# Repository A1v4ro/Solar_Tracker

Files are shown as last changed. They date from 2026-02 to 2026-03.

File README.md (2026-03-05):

# Sistema Autónomo Portátil de Control de Seguimiento Solar

## 📌 Descripción

Este proyecto corresponde al desarrollo de un **sistema autónomo portátil de seguimiento solar** orientado a maximizar la captación de energía en módulos fotovoltaicos de baja potencia.

El sistema integra control basado en lógica difusa, registro de datos, supervisión web y alimentación autónoma en un diseño compacto y funcional.

Proyecto académico desarrollado como trabajo final de Ingeniería Electrónica.

---

## 🎯 Objetivo

Diseñar e implementar un sistema electrónico portátil capaz de optimizar la orientación de un panel fotovoltaico mediante control inteligente, incrementando la eficiencia de captación energética respecto a un sistema fijo.

---

## 🧠 Arquitectura del Sistema

El sistema está compuesto por:

- Sensor solar basado en LDRs
- Controlador difuso tipo Sugeno
- Control PWM para motores DC
- Puente H L298N con aislamiento
- Sistema de registro de datos (microSD + RTC DS3231)
- Módulo de alimentación autónoma con batería 18650
- Interfaz HMI basada en servidor web
- Prototipo mecánico diseñado en SolidWorks

---

## 📂 Estructura del Repositorio

```
/Codigo Seguidor Solar      → Firmware del microcontrolador (platformio)
/XFUZZY controlador         → Diseño del controlador difuso (Xfuzzy)
/Mecanismo Seguidor Solar   → Modelo mecánico del prototipo (SolidWorks)
/PCB KiCad                  → Diseño de la PCB (esquemático y layout)
```

---

# 🔧 Firmware – PlatformIO

## Requisitos

- Visual Studio Code
- Extensión PlatformIO instalada
- Placa configurada en `platformio.ini`

## Cómo abrir el proyecto

1. Abrir VS Code  
2. Seleccionar:  
   File → Open Folder  
3. Abrir la carpeta `/Codigo Seguidor Solar`

PlatformIO detectará automáticamente la configuración del proyecto.

## Compilar el firmware

```bash
pio run
```

## Cargar al microcontrolador

```bash
pio run --target upload
```

## Cargar a la memoria interna del microcontrolador

```bash
pio run --target uploadfs
```

---

# 🧠 Controlador Difuso – Xfuzzy

El controlador fue diseñado utilizando Xfuzzy.

## Abrir el proyecto

1. Ejecutar Xfuzzy  
2. Abrir el archivo `.xfl` ubicado en la carpeta `/XFUZZY controlador`

## Generar código C

Dentro de Xfuzzy:

Tools → Code Generation  
Seleccionar lenguaje C  
Generar archivo fuente

El archivo generado se integra dentro del firmware en PlatformIO.

---

# 🏗 Diseño Mecánico – SolidWorks

La carpeta `/Mecanismo Seguidor Solar` contiene:

- Archivos de pieza (.SLDPRT)
- Ensamblajes (.SLDASM)

## Uso

1. Abrir SolidWorks  
2. Abrir el archivo de ensamblaje principal  
3. Mantener todas las piezas dentro de la misma carpeta

No requiere configuración adicional.

---

# 🖥 Diseño Electrónico – KiCad

El sistema electrónico fue diseñado utilizando KiCad.

La carpeta `/PCB KiCad` contiene:

- Archivo de proyecto (.kicad_pro)
- Esquemático (.kicad_sch)
- Diseño de PCB (.kicad_pcb)
- Archivos de fabricación (`/GERBER`)

## Requisitos

- KiCad versión 9 o superior (recomendado)

## Cómo abrir el proyecto

1. Abrir KiCad
2. Seleccionar "Open Project"
3. Abrir el archivo `.kicad_pro` ubicado en la carpeta `/PCB KiCad`

---

# ⚙ Características Técnicas

- Control difuso tipo Sugeno
- Defuzzificación por promedio ponderado
- Control PWM para motores DC
- Registro de datos en microSD
- RTC DS3231 para referencia temporal
- Alimentación autónoma con batería 18650
- Supervisión mediante servidor web

---

# 📊 Funcionamiento General

1. El sensor solar detecta el desbalance de iluminación.
2. El controlador difuso evalúa las reglas establecidas.
3. Se calcula la señal PWM mediante promedio ponderado.
4. Se acciona el motor para corregir la orientación.
5. Se registran las variables del sistema.
6. Se permite la supervisión mediante interfaz web, operando en dos modos de red:

   - **Modo STA (Station Mode):**
     El sistema se conecta a una red WiFi existente.  
     El acceso a la interfaz se realiza desde un ordenador mediante mDNS utilizando:
     
     http://solartracker.local

   - **Modo AP (Access Point Mode):**
     El sistema genera su propia red WiFi.  
     El acceso a la interfaz se realiza directamente mediante la dirección IP:
     
     http://192.168.4.1

---

# 📌 Estado del Proyecto

Proyecto académico finalizado.  
Sistema funcional validado experimentalmente.

---

# 👤 Autor

Alvaro Jhonny Ortega Quispe  
Ingeniería Electrónica UMSA

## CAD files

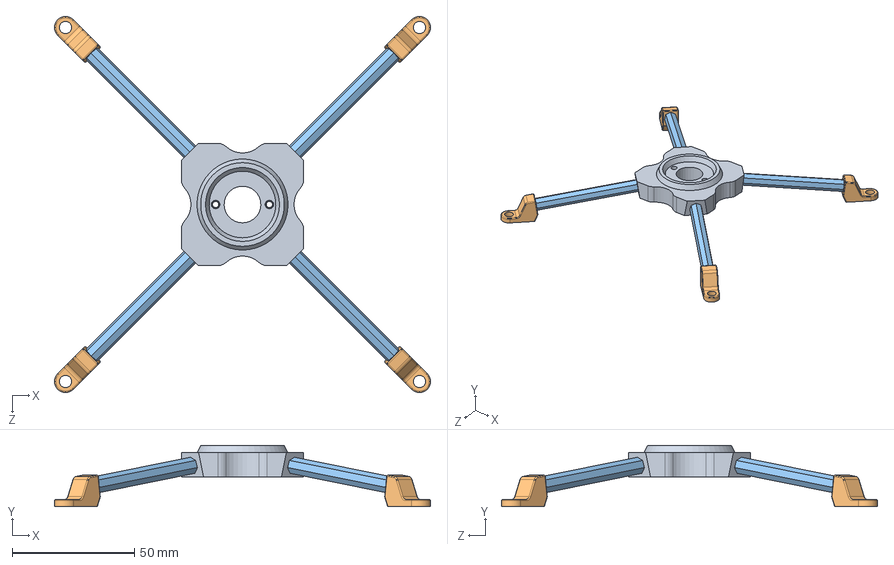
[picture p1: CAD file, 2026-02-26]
Mecanismo Seguidor Solar/base seguidor/base_seguidor.SLDASM
153.7 x 25.1 x 153.7 mm
conector_base
final_patas x 4
patas x 4
square nut thin grade b_din x 2

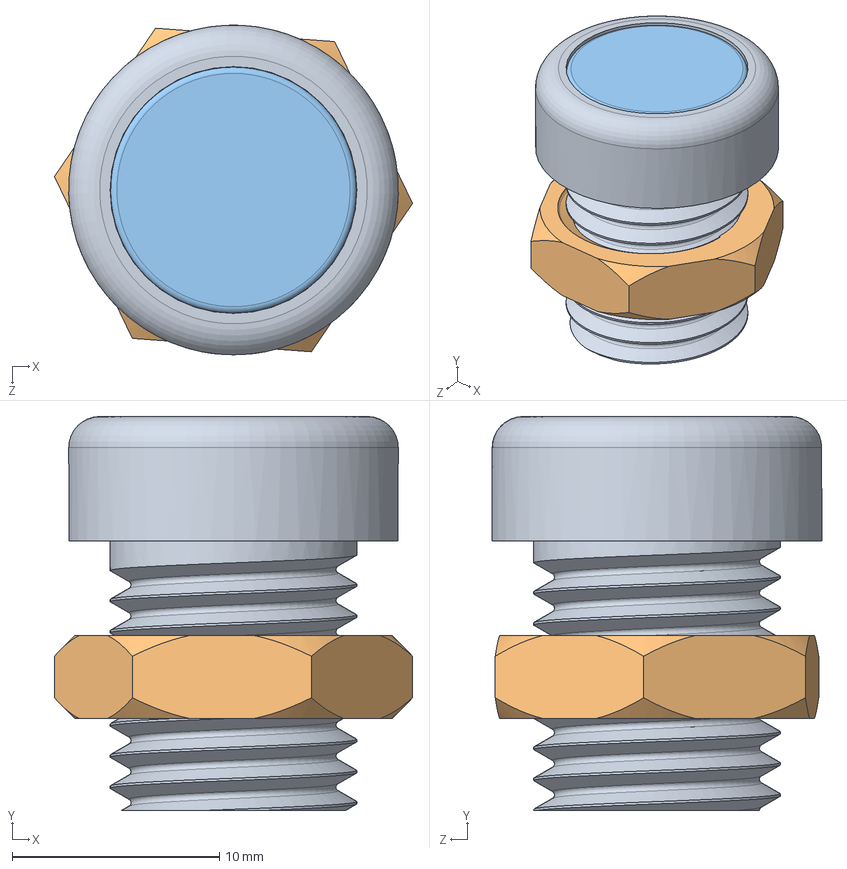
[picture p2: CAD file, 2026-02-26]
Mecanismo Seguidor Solar/piloto/piloto.SLDASM
17.3 x 19.0 x 15.9 mm
piloto_part1
piloto_part2
piloto_part3

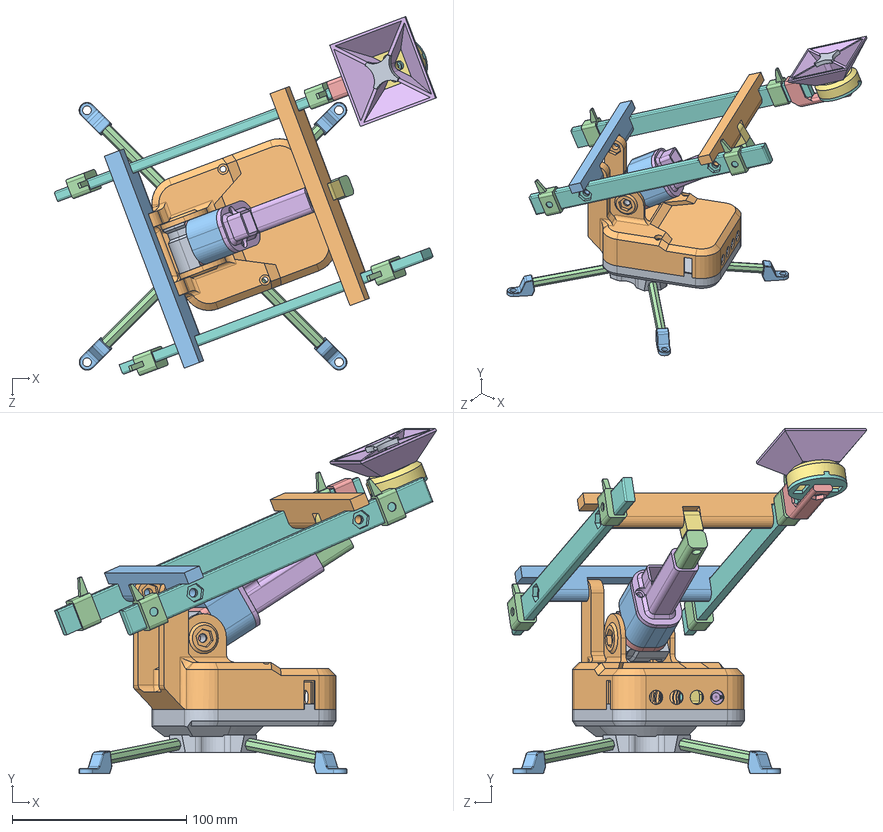
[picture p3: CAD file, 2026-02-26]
Mecanismo Seguidor Solar/stl/solar_tracker.SLDASM
219.3 x 198.3 x 206.1 mm
base_patas_bearing
corona_bearing
final_patas x 4
patas x 4
radial cylindrical roller bearing_iso
N20 DC MOTOR.step
sujetador_motor
tornillo_bearing_second
base_seguidor
tapa_seguidor
cubierta_motor
embolo
eje_actuador_fincarrera
tapa_cuerpo
eje
arm_cenit x 2
topes
sujetador_panel_sup
sujetador_panel_inf
sujetador_arm x 4
connector
cruz
cubierta
tapa
covertor
tapa_fincarrera

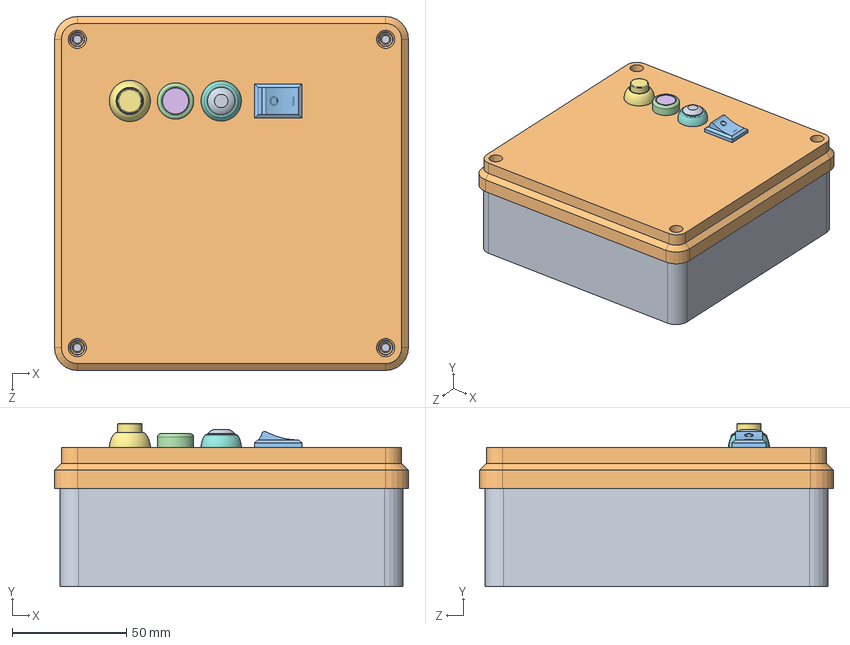
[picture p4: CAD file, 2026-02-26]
Mecanismo Seguidor Solar/box 15x15 ip65/CAJA-IP65.SLDASM
155.0 x 71.5 x 155.0 mm
box_bottom
tapa
Square Rocker Switch v2.step
piloto_part1
piloto_part2
piloto_part3
Button Yellow
Body.step
Body001.step
Body002 (Mirror #1).step
Body003.step
Body002.step
Body004.step

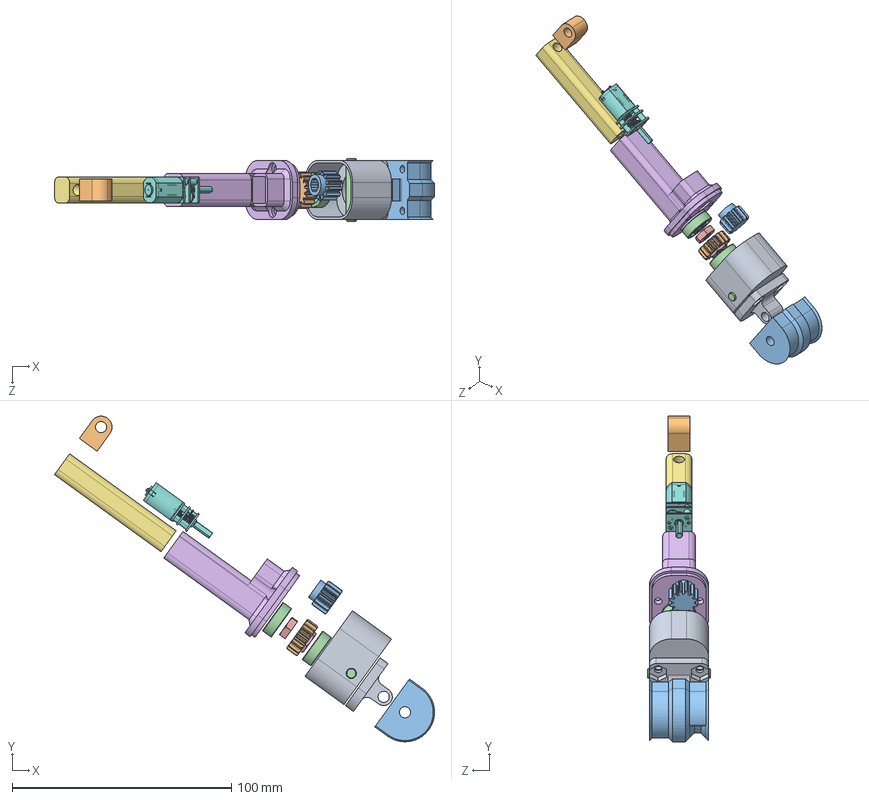
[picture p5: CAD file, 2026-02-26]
Mecanismo Seguidor Solar/actuador lineal/actuador_lineal.SLDASM
173.4 x 148.6 x 28.6 mm
cubierta_inferior_actuador
engranaje_tornillo
engranaje_motor
instrument ball bearing_68_am x 2
machine screw nut hex_ai x 3
cubierta_superior_actuador
vástago
N20 DC MOTOR.step
eje_actuador
conector_superior
eje_limitador

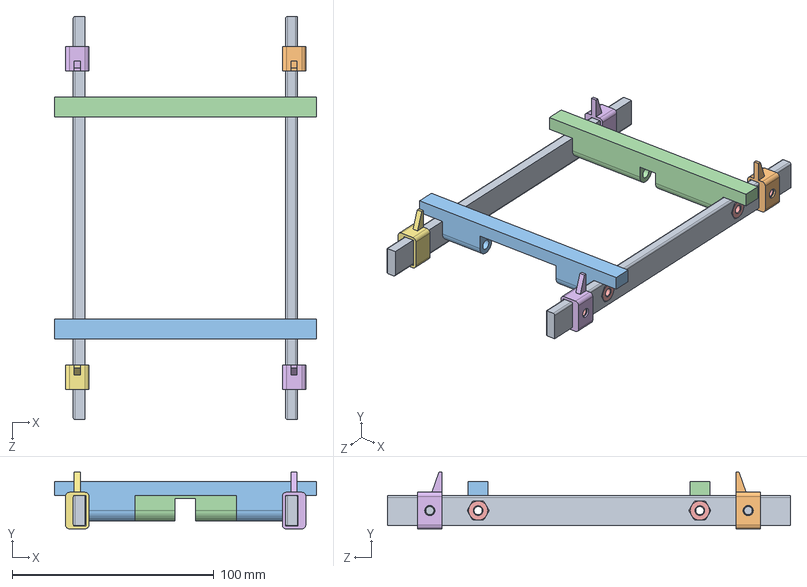
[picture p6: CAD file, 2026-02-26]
Mecanismo Seguidor Solar/base panel/base_panel.SLDASM
130.1 x 28.2 x 200.0 mm
viga_vertical x 2
sujetador_panel
viga_horizontal_inferior
viga_horizontal_superior
machine screw nut hex_ai x 8
Mirrorsujetador_panel x 2
MirrorMirrorsujetador_panel

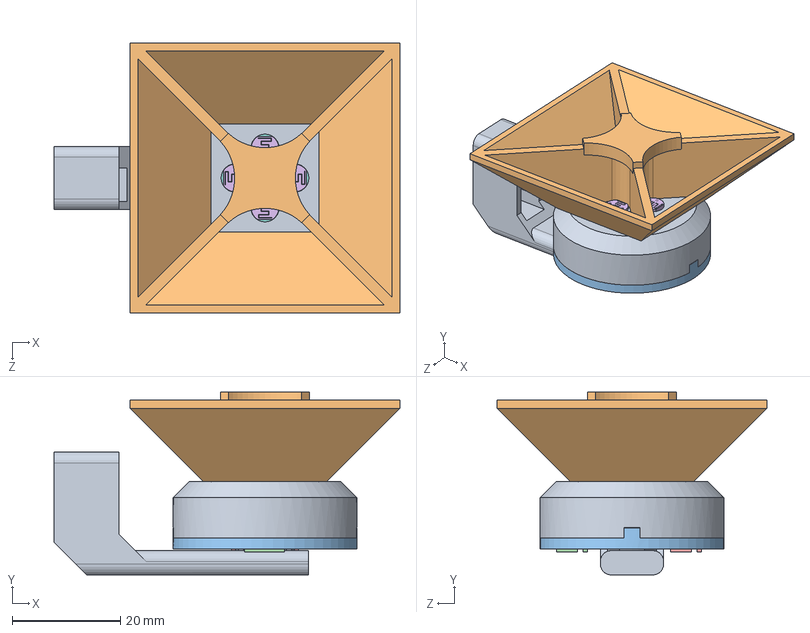
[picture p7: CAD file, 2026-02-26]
Mecanismo Seguidor Solar/sensor/sensor.SLDASM
64.0 x 33.8 x 49.9 mm
cubierta
cruz
tapa
JST_XH_B2B-XH-A_1x02_P2.50mm_Vertical.step
JST_XH_B4B-XH-A_1x04_P2.50mm_Vertical.step
R_LDR_5.1x4.3mm_P3.4mm_Vertical.step x 4
R_Axial_DIN0204_L3.6mm_D1.6mm_P7.62mm_Horizontal.step x 4
solarSensor_PCB.step
connector
covertor
machine screw nut hex_ai

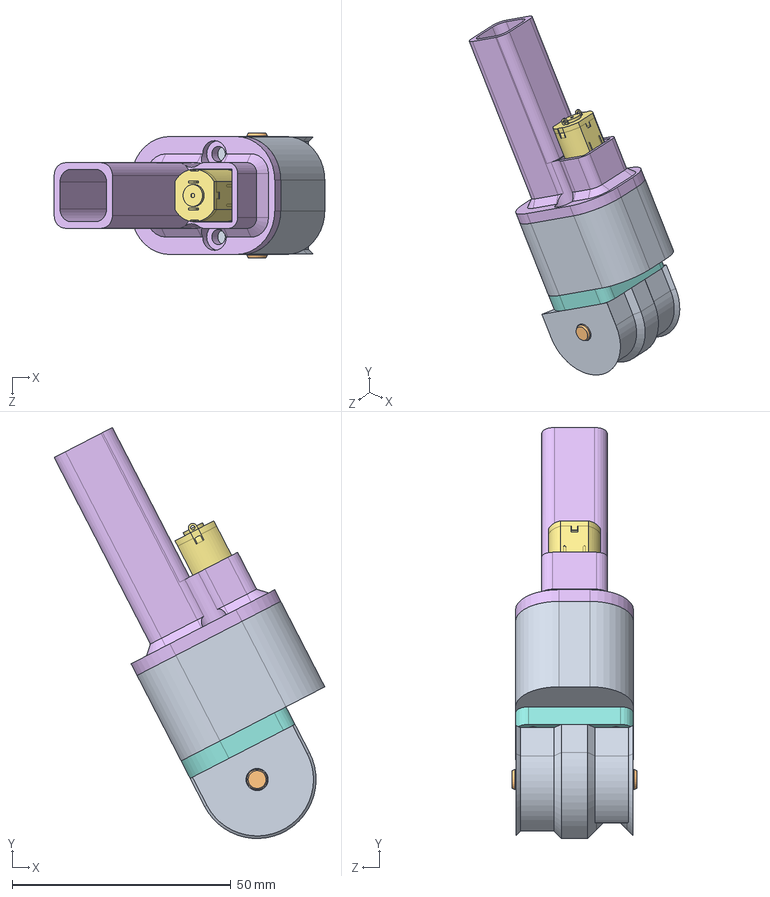
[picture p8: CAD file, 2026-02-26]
Mecanismo Seguidor Solar/actuador lineal/actuador_lineal_parcial.SLDASM
61.9 x 94.0 x 28.6 mm
cubierta_inferior_actuador
engranaje_tornillo
engranaje_motor
instrument ball bearing_68_am x 2
machine screw nut hex_ai x 2
cubierta_superior_actuador
N20 DC MOTOR.step
eje_actuador
eje_limitador

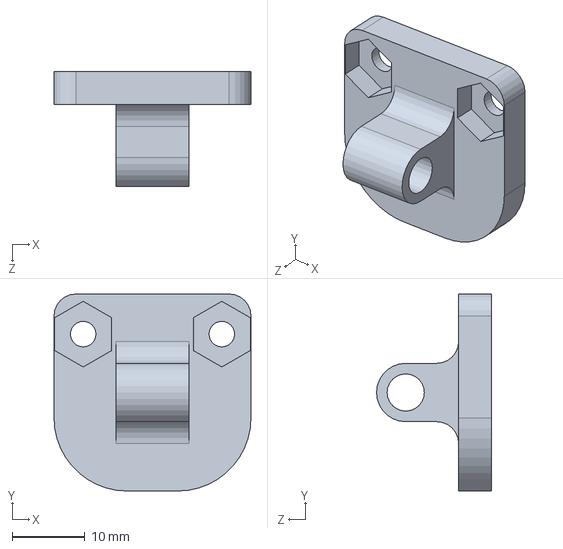
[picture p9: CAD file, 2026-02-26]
Mecanismo Seguidor Solar/actuador lineal/eje_actuador.SLDPRT
27.0 x 27.0 x 15.8 mm

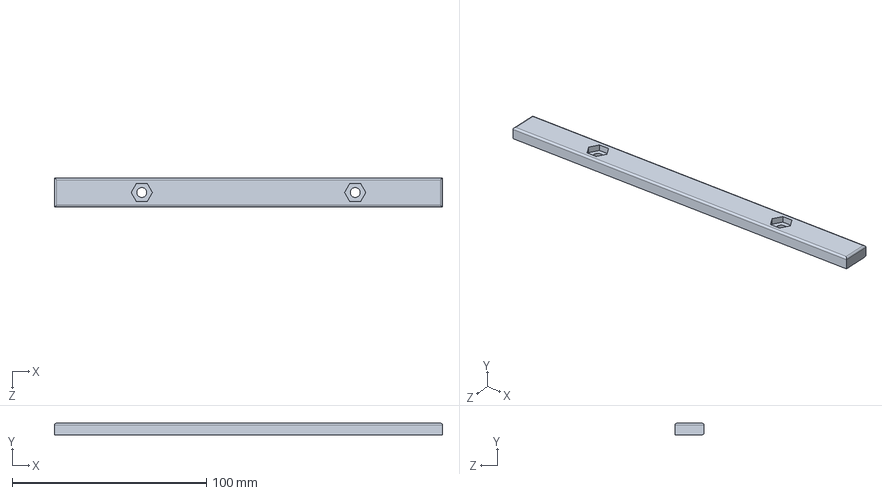
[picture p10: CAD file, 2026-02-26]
Mecanismo Seguidor Solar/base panel/viga_vertical.SLDPRT
200.0 x 6.00 x 15.0 mm

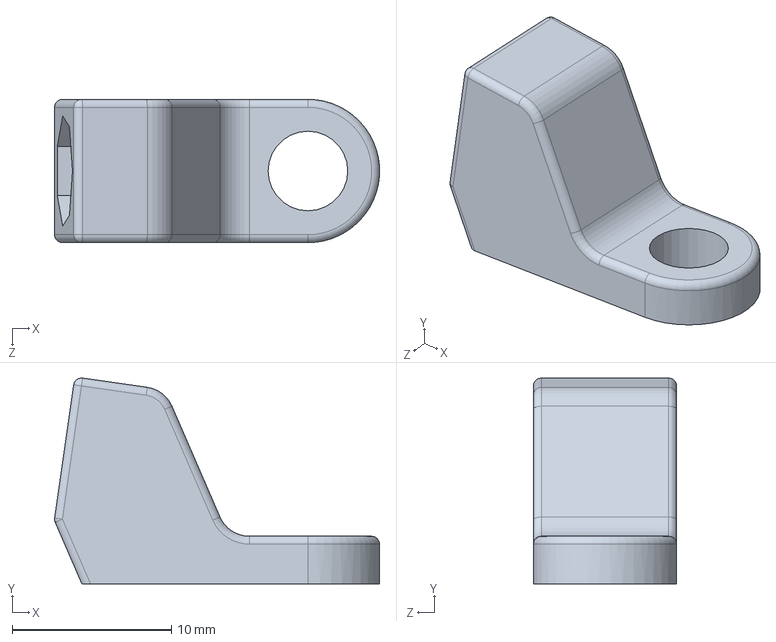
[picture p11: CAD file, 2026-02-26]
Mecanismo Seguidor Solar/base seguidor/final_patas.SLDPRT
20.4 x 12.9 x 9.00 mm

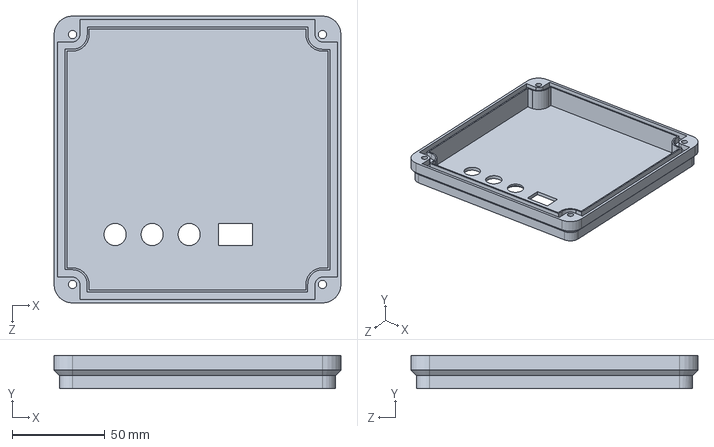
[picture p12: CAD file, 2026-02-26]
Mecanismo Seguidor Solar/box 15x15 ip65/tapa.SLDPRT
155.0 x 18.0 x 155.0 mm

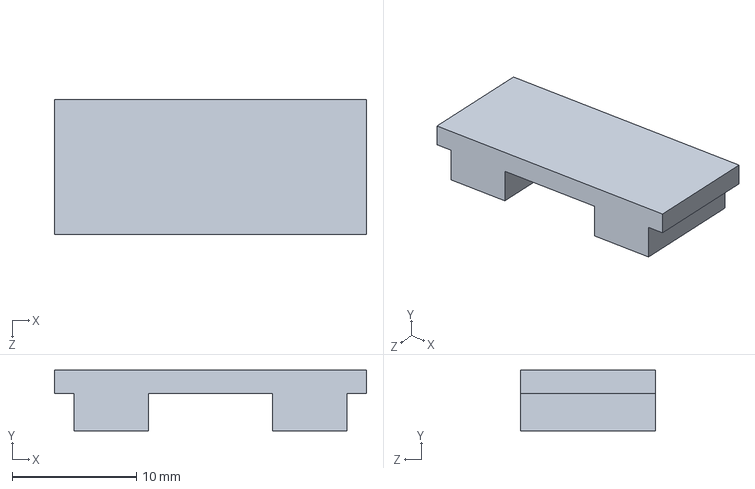
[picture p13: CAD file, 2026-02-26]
Mecanismo Seguidor Solar/cuerpo seguidor/tapa_fincarrera.SLDPRT
25.1 x 4.90 x 10.9 mm

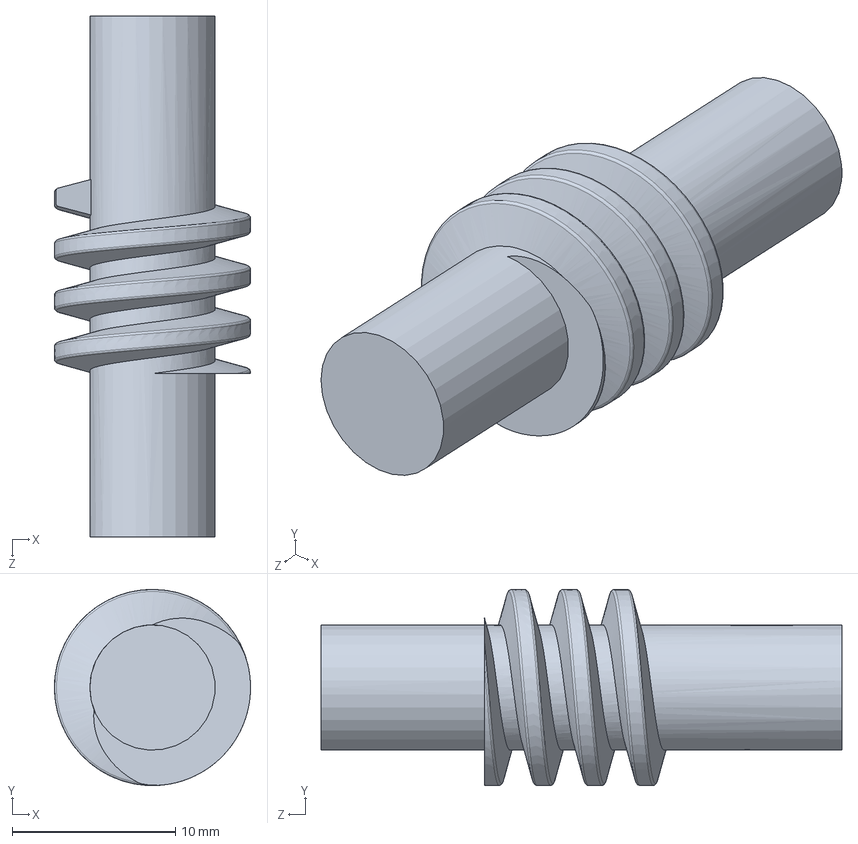
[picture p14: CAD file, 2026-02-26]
Mecanismo Seguidor Solar/diseño de mecanismos/tornillo.SLDPRT
12.0 x 12.0 x 31.9 mm

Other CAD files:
Mecanismo Seguidor Solar/moviiento_cenital.SLDPRT
Mecanismo Seguidor Solar/piloto/piloto_part3.SLDPRT
Mecanismo Seguidor Solar/sensor/cruz.SLDPRT
Mecanismo Seguidor Solar/stl/espaciador_sup.SLDPRT
Mecanismo Seguidor Solar/UPS_18650_1s.SLDPRT
Mecanismo Seguidor Solar/actuador lineal/actuador_lineal.SLDDRW
Mecanismo Seguidor Solar/actuador lineal/conector_superior.SLDPRT
Mecanismo Seguidor Solar/actuador lineal/cubierta_inferior_actuador.SLDPRT
Mecanismo Seguidor Solar/actuador lineal/cubierta_superior_actuador.SLDPRT
Mecanismo Seguidor Solar/actuador lineal/eje_limitador.SLDPRT
Mecanismo Seguidor Solar/actuador lineal/engranaje_motor.SLDPRT
Mecanismo Seguidor Solar/actuador lineal/engranaje_tornillo.SLDPRT
Mecanismo Seguidor Solar/actuador lineal/vástago.SLDPRT
Mecanismo Seguidor Solar/base panel/MirrorMirrorsujetador_panel.SLDPRT
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

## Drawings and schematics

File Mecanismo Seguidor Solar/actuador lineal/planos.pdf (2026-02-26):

D D

6

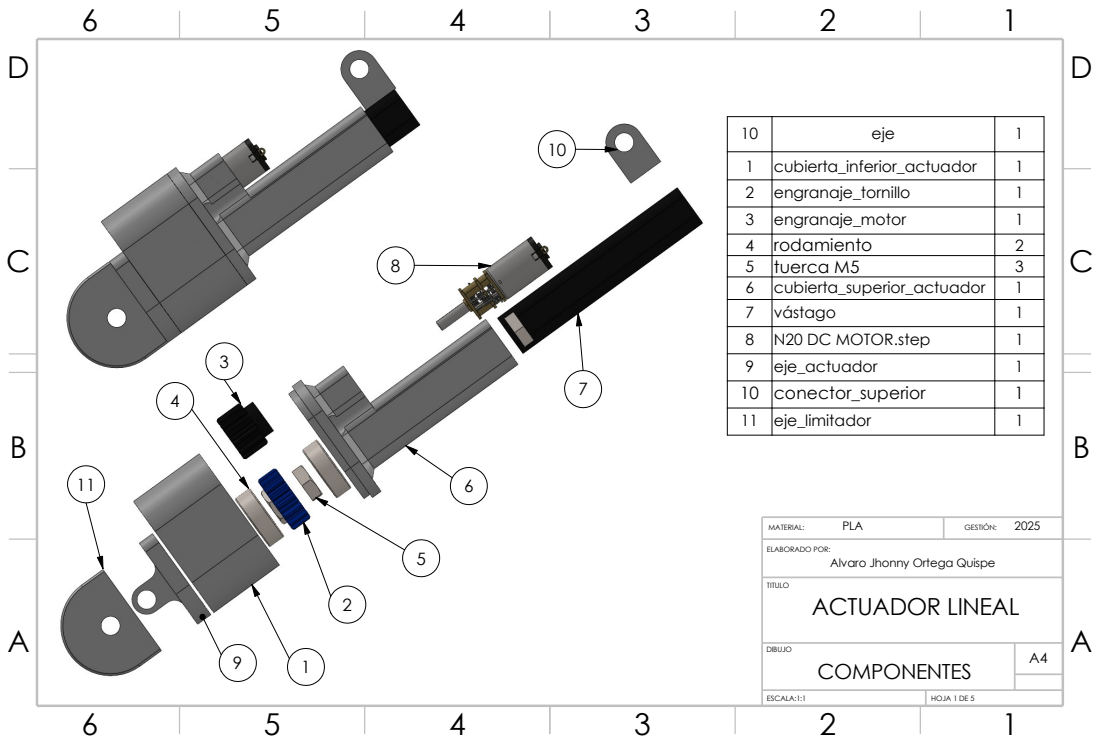
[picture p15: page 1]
GESTIÓN:; TITULO; DIBUJO; ESCALA:1:1; HOJA 1 DE 5; PLA; COMPONENTES; ACTUADOR LINEAL; MATERIAL:; ELABORADO POR:

10 | eje | 1
1 | cubierta_inferior_actuador | 1
2 | engranaje_tornillo | 1
3 | engranaje_motor | 1
4 | rodamiento | 2
5 | tuerca M5 | 3
6 | cubierta_superior_actuador | 1
7 | vástago | 1
8 | N20 DC MOTOR.step | 1
9 | eje_actuador | 1
10 | conector_superior | 1
11 | eje_limitador | 1

Alvaro Jhonny Ortega Quispe

D D

6

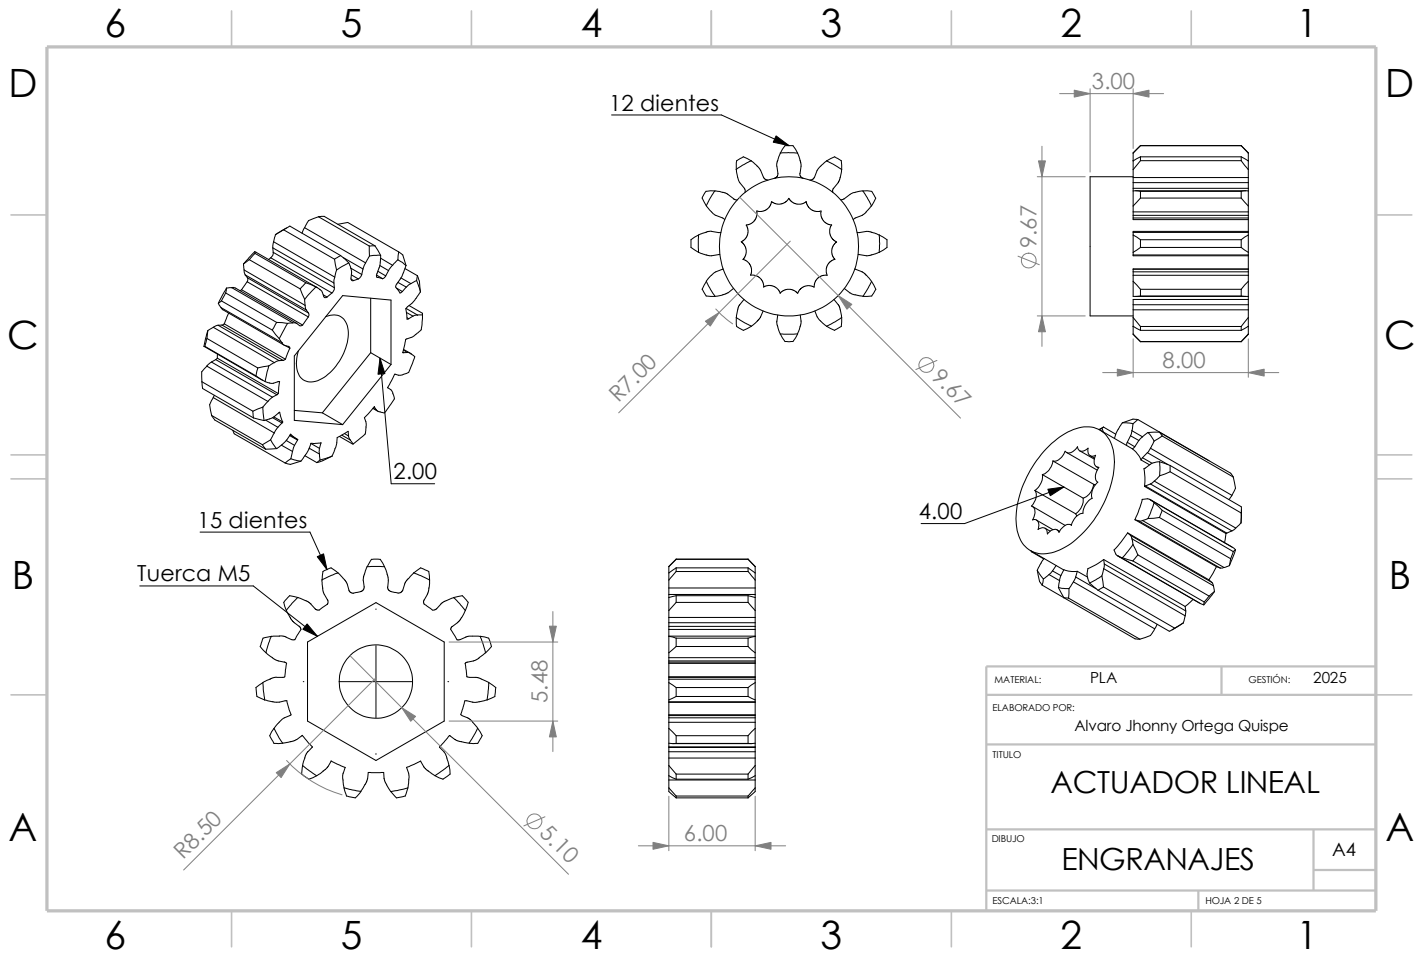
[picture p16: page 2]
GESTIÓN:; TITULO; DIBUJO; ESCALA:3:1; HOJA 2 DE 5; PLA; ENGRANAJES; ACTUADOR LINEAL A A; MATERIAL:; ELABORADO POR:; 12 dientes; 15 dientes; Tuerca M5

Alvaro Jhonny Ortega Quispe

D D

6

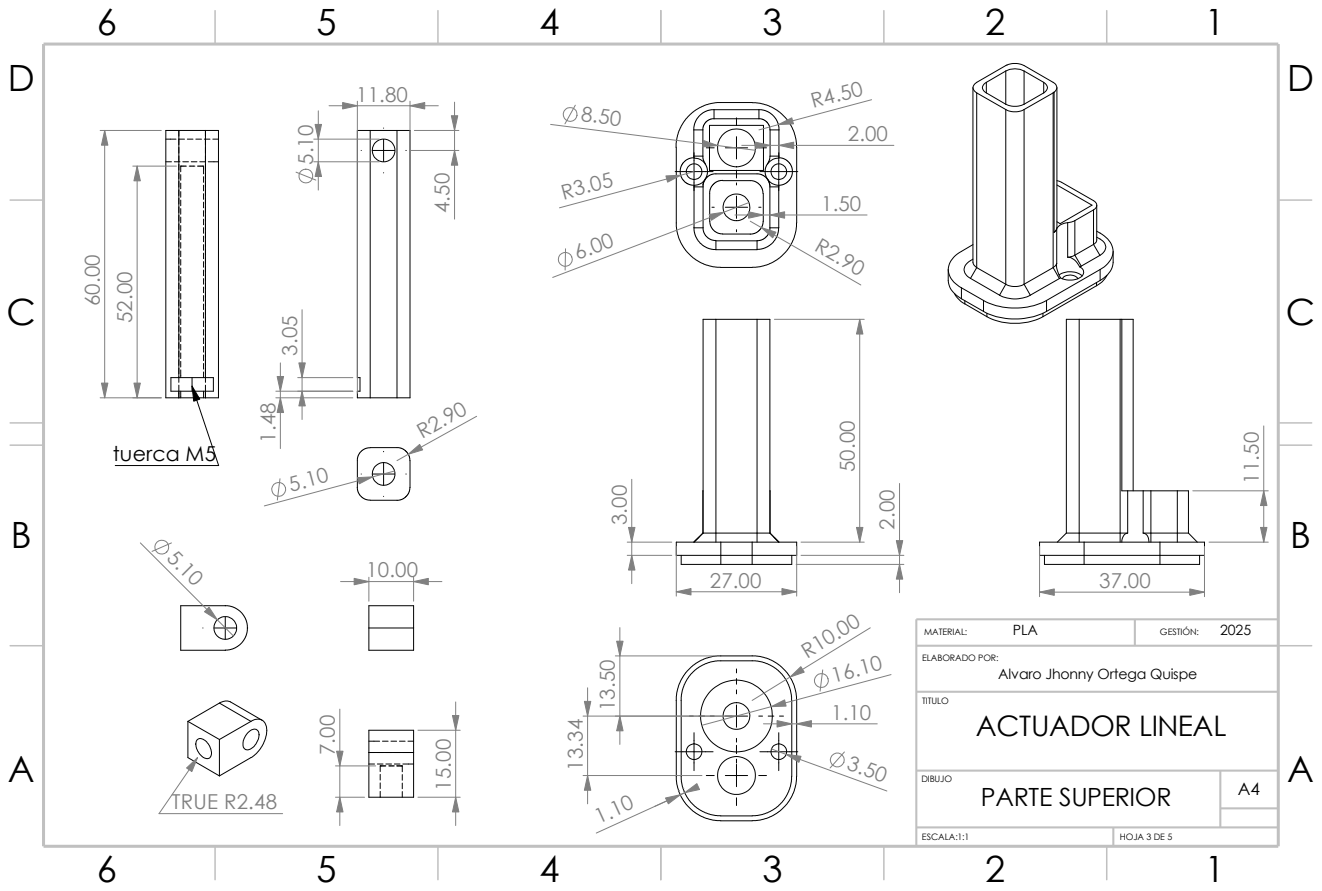
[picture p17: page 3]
GESTIÓN:; TITULO; DIBUJO; ESCALA:1:1; HOJA 3 DE 5; PLA; PARTE SUPERIOR; ACTUADOR LINEAL A A; MATERIAL:; ELABORADO POR:; TRUE R2.48; tuerca M5 ⁶⁰.00

Alvaro Jhonny Ortega Quispe

D D

6

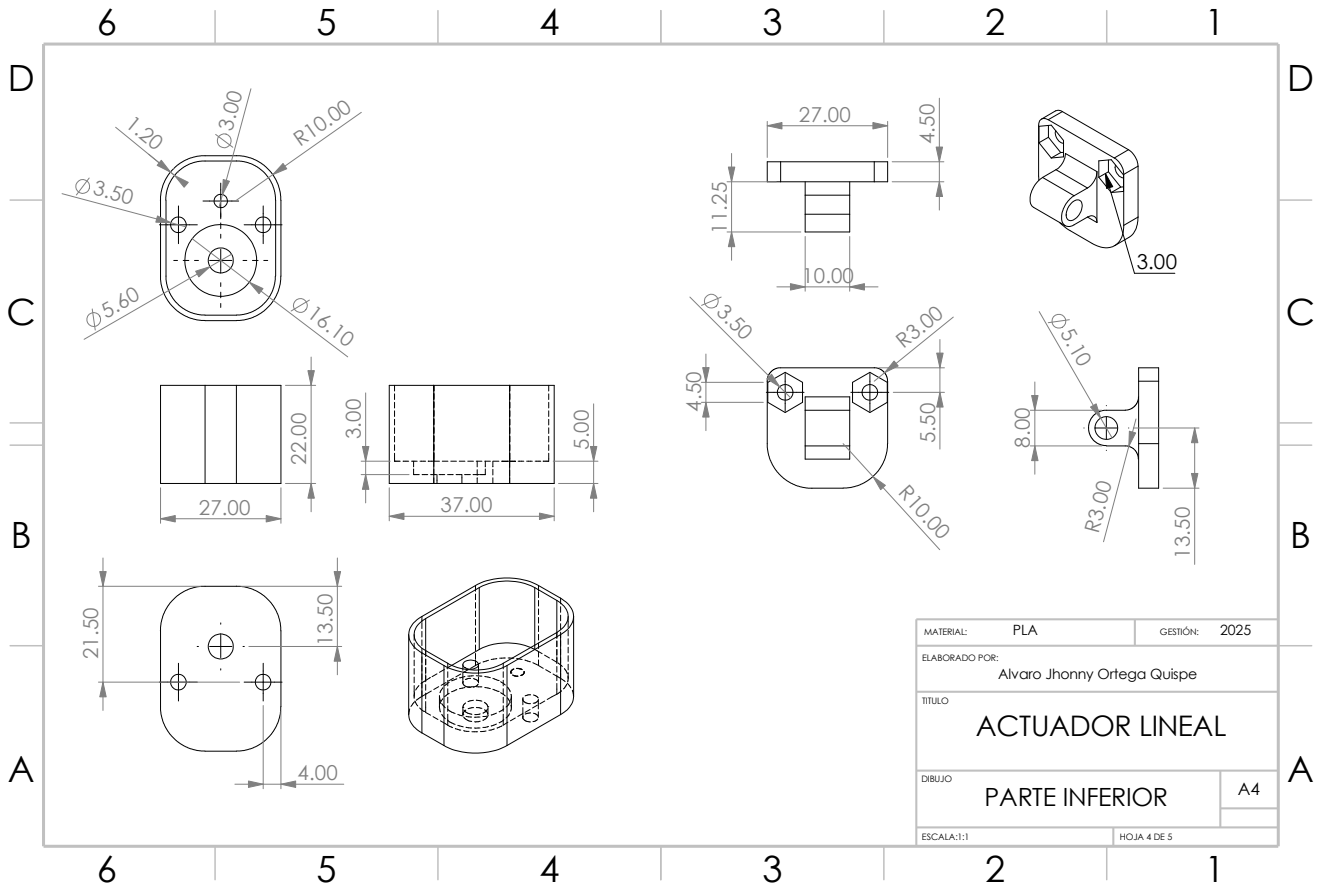
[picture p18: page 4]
GESTIÓN:; TITULO; DIBUJO; ESCALA:1:1; HOJA 4 DE 5; PLA; PARTE INFERIOR; ACTUADOR LINEAL A A; MATERIAL:; ELABORADO POR:

Alvaro Jhonny Ortega Quispe

D D

6

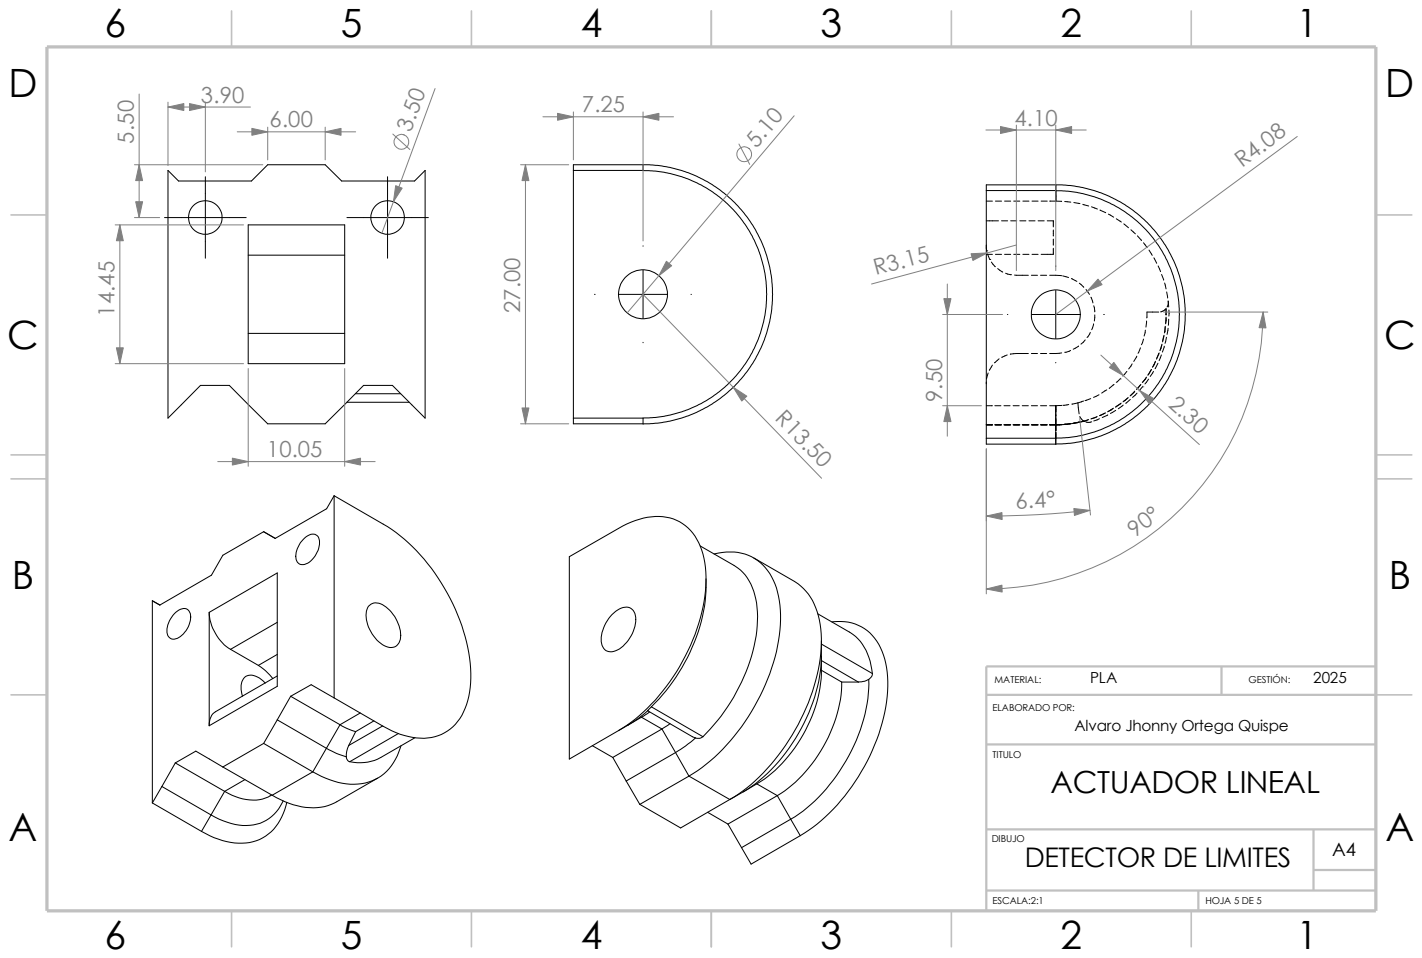
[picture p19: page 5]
GESTIÓN:; TITULO; ESCALA:2:1; HOJA 5 DE 5; PLA; ACTUADOR LINEAL A A; MATERIAL:; ELABORADO POR:

Alvaro Jhonny Ortega Quispe

DIBUJO
DETECTOR DE LIMITES

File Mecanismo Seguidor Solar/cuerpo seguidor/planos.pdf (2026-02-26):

D D

6

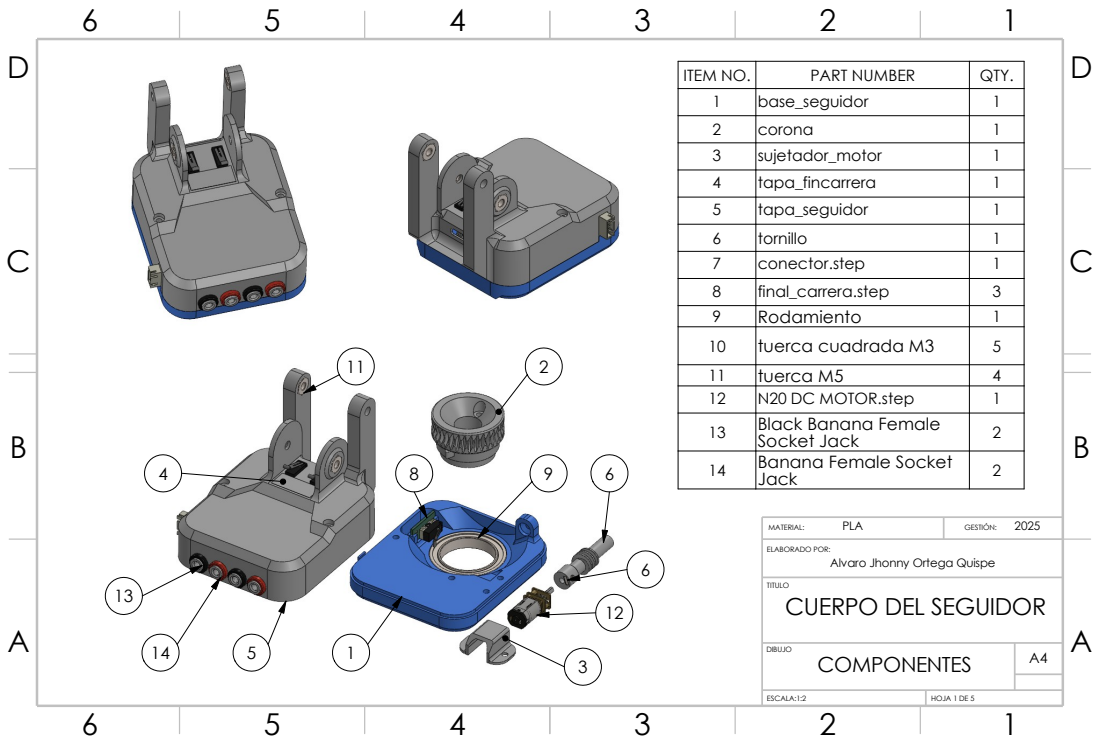
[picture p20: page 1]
HOJA 1 DE 5; GESTIÓN:; ESCALA:1:2; TITULO; DIBUJO; PLA; COMPONENTES; MATERIAL:

ITEM NO. | PART NUMBER | QTY.
1 | base_seguidor | 1
2 | corona | 1
3 | sujetador_motor | 1
4 | tapa_fincarrera | 1
5 | tapa_seguidor | 1
6 | tornillo | 1
7 | conector.step | 1
8 | final_carrera.step | 3
9 | Rodamiento | 1
10 | tuerca cuadrada M3 | 5
11 | tuerca M5 | 4
12 | N20 DC MOTOR.step | 1
13 Black Banana Female | Socket Jack | 2
14 Banana Female Socket | Jack | 2

ELABORADO POR:
CUERPO DEL SEGUIDOR

Alvaro Jhonny Ortega Quispe

D D

6

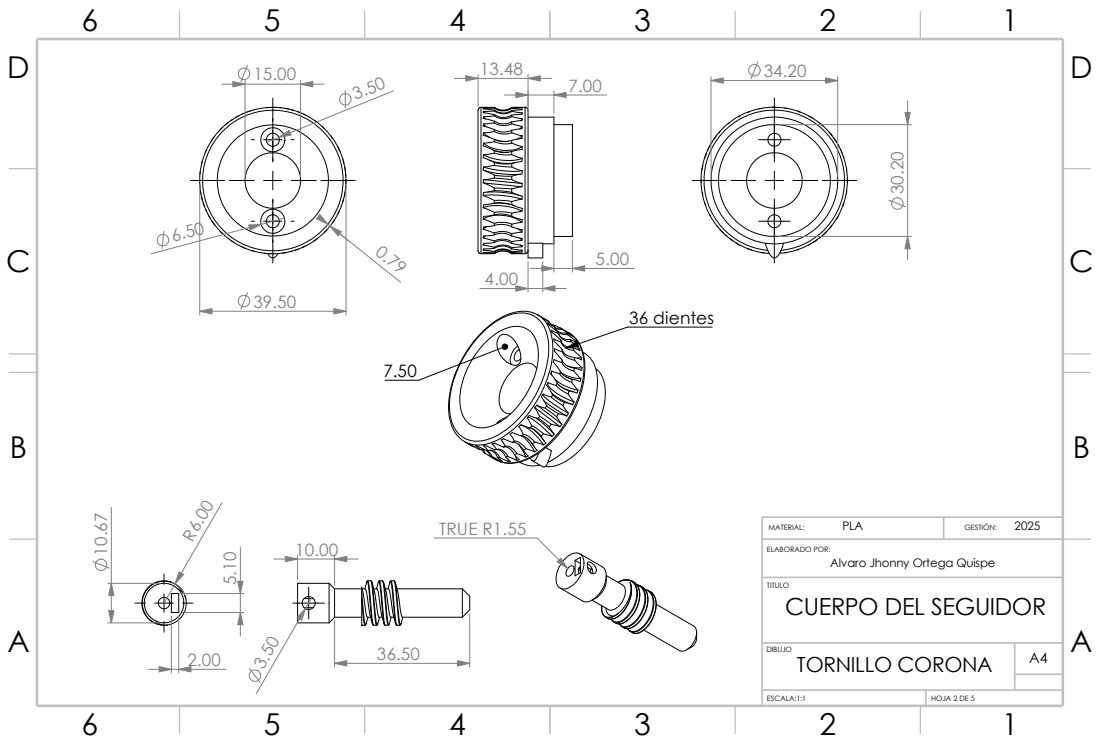
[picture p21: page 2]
GESTIÓN:; TITULO; DIBUJO; ESCALA:1:1; HOJA 2 DE 5; PLA; TORNILLO CORONA; MATERIAL:; 36 dientes; TRUE R1.55

ELABORADO POR:
CUERPO DEL SEGUIDOR

Alvaro Jhonny Ortega Quispe

D D

6

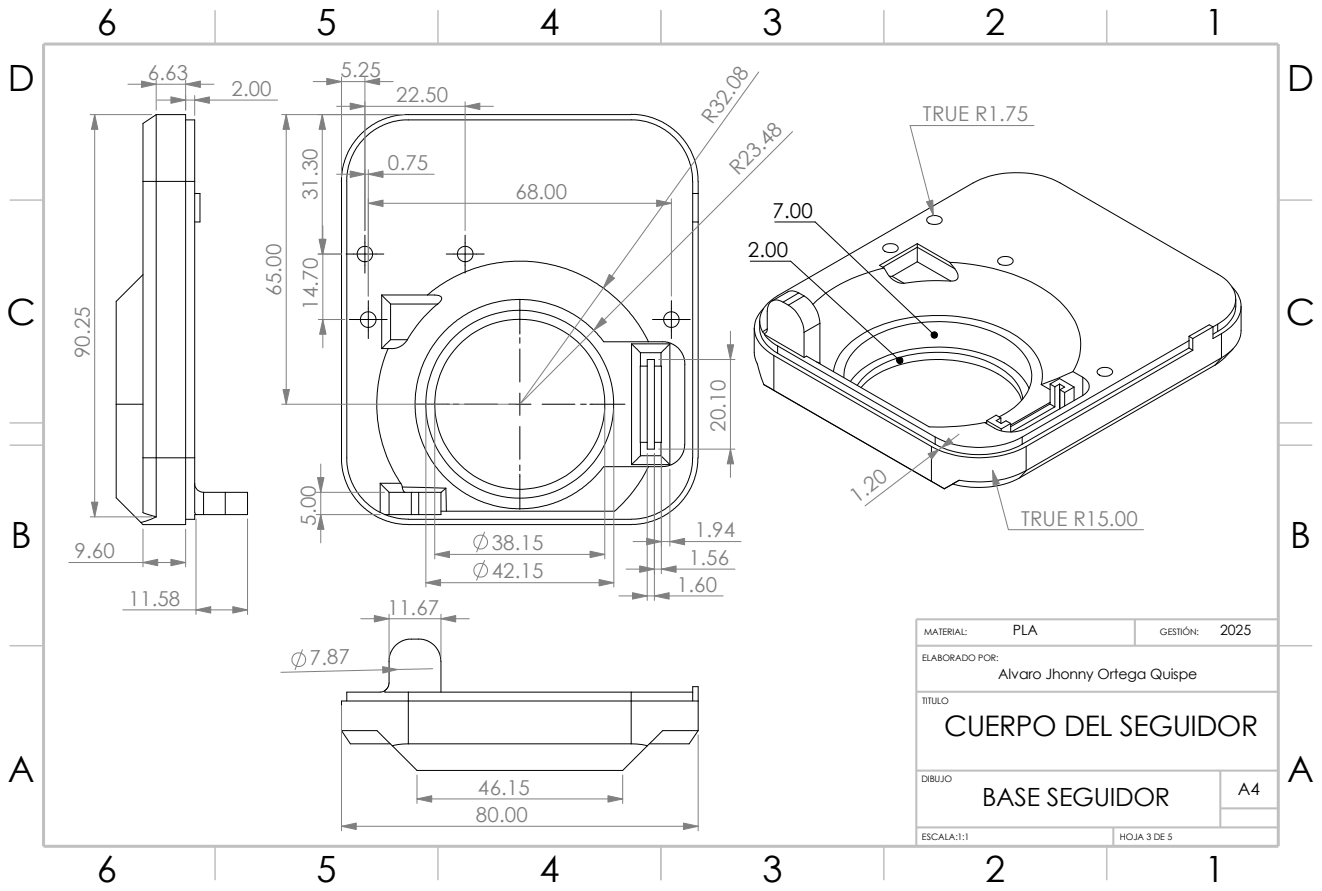
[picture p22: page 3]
GESTIÓN:; TITULO; DIBUJO; ESCALA:1:1; HOJA 3 DE 5; PLA; BASE SEGUIDOR; MATERIAL:; TRUE R1.75; TRUE R15.00

ELABORADO POR:
CUERPO DEL SEGUIDOR

Alvaro Jhonny Ortega Quispe

D D

6

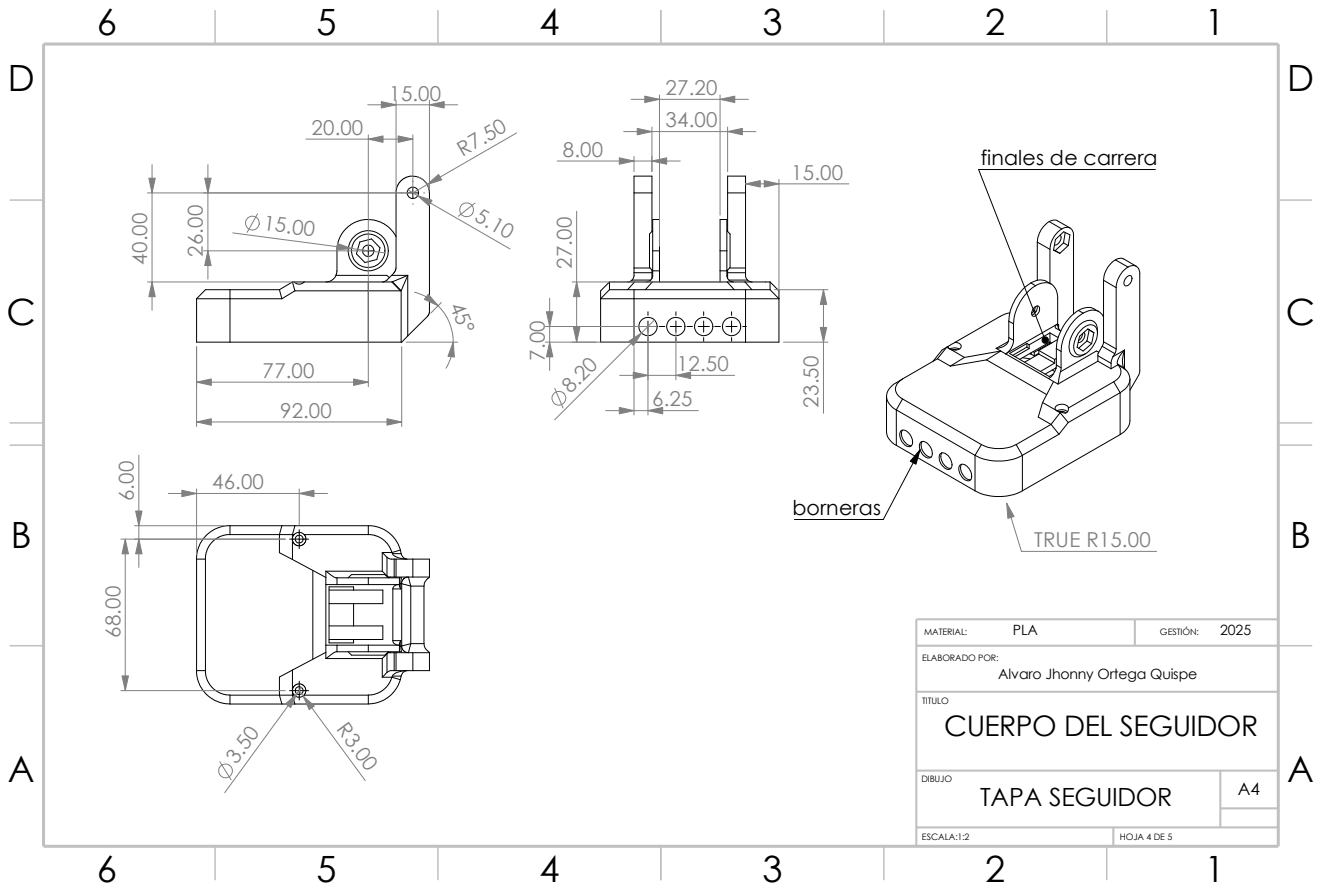
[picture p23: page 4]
GESTIÓN:; TITULO; DIBUJO; ESCALA:1:2; HOJA 4 DE 5; PLA; TAPA SEGUIDOR; MATERIAL:; borneras; TRUE R15.00

15.00 finales de carrera

ELABORADO POR:
CUERPO DEL SEGUIDOR

Alvaro Jhonny Ortega Quispe

D D

6

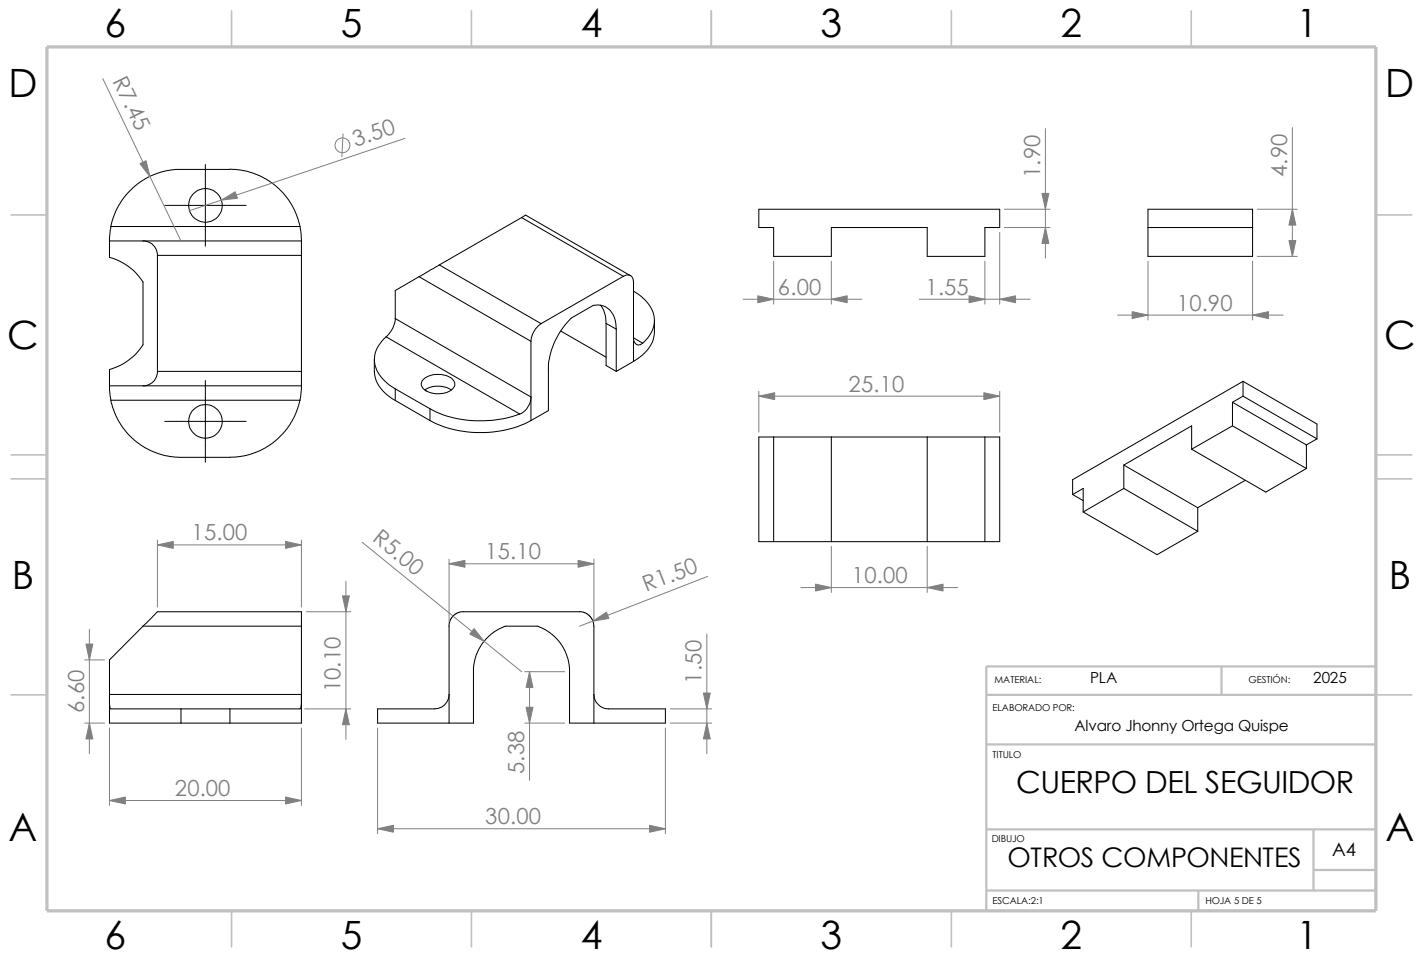
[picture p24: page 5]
GESTIÓN:; TITULO; DIBUJO; ESCALA:2:1; HOJA 5 DE 5; PLA; OTROS COMPONENTES; MATERIAL:

ELABORADO POR:
CUERPO DEL SEGUIDOR

Alvaro Jhonny Ortega Quispe

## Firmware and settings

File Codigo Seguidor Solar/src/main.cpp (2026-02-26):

#include <Arduino.h>
#include <cmath>
#include <freertos/FreeRTOS.h>
#include <freertos/task.h>
#include <freertos/timers.h>
#include <freertos/queue.h>

#include "DebugLog.h"
#include "MemoryData.h"
#include "DataLogger.h"
#include "WiFiManager.h"
#include "WebInterface.h"
#include "MotorsManager.h"
#include "SensorManager.h"
#include "OTAManager.h"
#include "fuzzyControl.h"

#define ADC_DOWN 35         // Pin analógico LDR inferior
#define ADC_RIGHT 36        // Pin analógico LDR derecho
#define ADC_UP 39           // Pin analógico LDR superior
#define ADC_LEFT 34         // Pin analógico LDR izquierdo

#define DIR_H 25            // Pin para dirección horizontal
#define SPEED_H 26          // Pin PWM horizontal
#define DIR_V  27           // Pin para dirección vertical
#define SPEED_V 14          // Pin PWM vertical
#define END_V 13            // Fin de carrera maximo vertical

#define CS_SD 5             // Pin de SD
#define END_H 17            // Fin de carrera maximo horizontal
#define ENABLE_HMI 16       // Pin para control del HMI (servidor)
#define START_V 4           // Fin de carrera inicio vertical
#define LED_PIN 0           // Piloto de estado
#define SET_MODE 15         // Pulsador de modo

#define TASK_START_SIGNAL  1
#define TASK_STOP_SIGNAL   2
#define TASK_UPDATE_INTERVAL 3
#define WEB_SERVER 80

volatile unsigned long newControlInterval;
enum LedMode {
    LED_AUTOMATIC,      // Parpadeo lento 
    LED_MANUAL,         // Parpadeo medio 
    LED_HOMING          // Parpadeo rápido 
};
volatile LedMode currentLedMode;                        // Modo de parpadeo de led
volatile bool azimutDirection = false;                   // ultima direccion registrada por el final de carrera en azimut (false = antihorario, true = horario)
volatile bool isHoming = false;

TaskHandle_t buttonTaskHandle = NULL;
TaskHandle_t controlTaskHandle = NULL;
TaskHandle_t loggingTaskHandle = NULL;
TaskHandle_t taskManagerHandle = NULL;
TaskHandle_t webControlHandle = NULL;
TaskHandle_t ledTaskHandle = NULL;
TaskHandle_t positionTaskHandle = NULL;

AsyncWebServer server(WEB_SERVER);
MemoryData memory;
MotorsManager motors(DIR_H, SPEED_H, DIR_V, SPEED_V);
SensorManager sensors(ADC_UP, ADC_DOWN, ADC_RIGHT, ADC_LEFT);
DataLogger logger;
WiFiManager wifiManager(memory);
WebInterface webInterface(server, logger, wifiManager, memory, motors, sensors);
OTAManager otaManager(&server);

// ************************
//  SINCRONIZACION DE TIEMPO (uint32_t para tiempo Unix se desbordará en 2038)
// ************************
uint32_t syncRTC() {
    uint32_t intervalSec = memory.logInterval / 1000;
    DateTime now = logger.getCurrentTime();
    uint32_t nowUnix = now.unixtime();

    // Calcular próximo intervalo exacto
    uint32_t nextLogUnix = ((nowUnix / intervalSec) + 1) * intervalSec;
    uint32_t remainingTimeMs = (nextLogUnix - nowUnix) * 1000;

    return remainingTimeMs;
};

// ************************
//  GESTION DEL HMI 
// ************************
void webControlTask(void *pvParameters) {
    static bool currentWebState = false;
    bool webState;                     // Estados de activacion de wifi
    uint32_t notifiedValue = 0;
    for (;;) {
        xTaskNotifyWait(0x00, 0xFFFFFFFF, &notifiedValue, portMAX_DELAY);

        // Notificación desde ISR 
        if (notifiedValue == 1) {
            DBG_PRINTLN("[HMI] Notificación desde ISR");
            webState = digitalRead(ENABLE_HMI); 
            if (webState && !currentWebState) {
                wifiManager.begin();
                webInterface.begin();
                otaManager.begin();
                currentWebState = true;
                DBG_PRINTLN("[HMI] WebServer ACTIVADO");
            } else if (!webState && currentWebState) {
                webInterface.stopWeb();
                wifiManager.disconnect();
                currentWebState = false;
                DBG_PRINTLN("[HMI] WebServer DESACTIVADO");
            }
        }
        // Notificación desde Web
        else if (notifiedValue == 2){
            DBG_PRINTLN("[HMI] Notificación desde Web");
            wifiManager.startClientMode(); 
        }
    }
}

// ************************
//  TAREA DE REGISTRO DE DATOS
// ************************
void loggingTask(void *pvParameters) {
    TickType_t logDelay;
    uint32_t notifiedValue = 0;
    TickType_t startTick = 0, endTick = 0, waitTicks = 0;

    for (;;) {
        DBG_PRINTF("[LOG] Esperando señal de inicio...\n");

        // Espera hasta recibir una señal START
        xTaskNotifyWait(0x00, 0xFFFFFFFF, &notifiedValue, portMAX_DELAY);

        if (notifiedValue != TASK_START_SIGNAL && notifiedValue != TASK_UPDATE_INTERVAL) continue;
        DBG_PRINTF("[LOG] Registro iniciado.\n");

        // Sincronización inicial con RTC
        logDelay = pdMS_TO_TICKS(syncRTC());
        DBG_PRINTF("[LOG] Sincronizando con RTC, esperando %lu ms\n", pdTICKS_TO_MS(logDelay));

        // Bucle de registro periódico
        for (;;) {
            BaseType_t notified = xTaskNotifyWait(0x00, 0xFFFFFFFF, &notifiedValue, logDelay);
            startTick = xTaskGetTickCount();
            if (notified == pdTRUE) {
                if (notifiedValue == TASK_STOP_SIGNAL) {
                    DBG_PRINTF("[LOG] Registro detenido.\n");
                    break; // vuelve a la espera del próximo START
                } else if (notifiedValue == TASK_UPDATE_INTERVAL) {
                    logDelay = pdMS_TO_TICKS(syncRTC());
                    DBG_PRINTF("[LOG] Sincronizando con RTC, esperando %lu ms\n", pdTICKS_TO_MS(logDelay));
                    continue; // finaliza la iteracion del for actual
                }
            }
            logDelay = pdMS_TO_TICKS(memory.logInterval);

            DateTime  currentTime = logger.getCurrentTime();                    // Obtener la hora actual
            std::vector<float> sensorData = sensors.readAllSensors();
            logger.saveSensorData(currentTime, sensorData);
            DBG_PRINTF("[LOG] Datos guardados: %02d/%02d %02d:%02d, Ecenit: %d, Eazimut: %d\n",
                        currentTime.day(), currentTime.month(),
                        currentTime.hour(), currentTime.minute(),
                        sensors.getEcenit(), sensors.getEazimut());
            endTick = xTaskGetTickCount();
            logDelay = logDelay - endTick + startTick;
        }
    }
}

// ************************
//  SINCRONIZACION PARA EL CONTROL 
// ************************
TickType_t controlSync(){
    const uint32_t controlTime = 10000;
    if (memory.operationType == "sync"){
        uint32_t syncDelayMs = syncRTC();
        return pdMS_TO_TICKS(syncDelayMs > controlTime ? syncDelayMs - controlTime : syncDelayMs + memory.logInterval - controlTime);
    } else return pdMS_TO_TICKS(memory.controlInterval);
}

// ************************
//  HTAREA DE CONTROL DIFUSO (MODO AUTOMATICO) 
// ************************
void controlTask(void *pvParameters) {
    TickType_t controlDelay;
    uint32_t notifiedValue = 0;
    const TickType_t sampleTime = pdMS_TO_TICKS(5);
    float Dcenit = 0, Dazimut = 0;
    float Ecenit = 0, Eazimut = 0;
    double outCenit = 0, outAzimut = 0;                           
    float Ecenit_old = 0, Eazimut_old = 0;
    TickType_t startTick = 0, endTick = 0, waitTicks = 0;
    float dt, currentTime = 0, lastTime;
    uint8_t speed_cenit, speed_azimut, dir_cenit, dir_azimut;
    const float deadZone = 1.0f;      // rango de -1 a 1
    const uint8_t deadZoneLimit = 7;  // lecturas consecutivas para parar
    uint8_t deadZoneCounter = 0;

    for (;;) {
        DBG_PRINTF("[CTRL] Esperando señal de inicio...\n");

        // Espera hasta recibir una señal START
        xTaskNotifyWait(0x00, 0xFFFFFFFF, &notifiedValue, portMAX_DELAY);

        if (notifiedValue != TASK_START_SIGNAL) continue;
        DBG_PRINTF("[CTRL] Control iniciado.\n");

        controlDelay = controlSync();

        for (;;) {
            startTick = xTaskGetTickCount();
            deadZoneCounter = 0;
            lastTime = millis();

            while (deadZoneCounter <= deadZoneLimit) {
                if (xTaskNotifyWait(0x00, 0xFFFFFFFF, &notifiedValue, 0) == pdTRUE) {
                    if (notifiedValue == TASK_STOP_SIGNAL) {
                        motors.stop();
                        DBG_PRINTF("[CTRL] Paro de Emergencia\n");
                        goto wait_for_start;
                    }
                }
                sensors.updateSolarSensor();
                Ecenit = sensors.getEcenit() - sensors.offsetCenit;
                Eazimut = sensors.getEazimut() - sensors.offsetAzimut;
                DBG_PRINTF("Ecenit: %f, Eazimut: %f\n", Ecenit, Eazimut); 
                currentTime = millis();
                dt = (currentTime - lastTime) / 1000.0f;
                lastTime = currentTime;

                Dcenit = (Ecenit - Ecenit_old) / dt;
                Dazimut = (Eazimut - Eazimut_old) / dt;
                Ecenit_old = Ecenit;
                Eazimut_old = Eazimut;

                fuzzyControlInferenceEngine(Ecenit, Dcenit, Eazimut, Dazimut, &outCenit, &outAzimut);

                speed_cenit  = (uint8_t) round(fabs(outCenit));
                speed_azimut = (uint8_t) round(fabs(outAzimut));
                dir_cenit  = (outCenit >= 0) ? 2 : 1;
                dir_azimut = (outAzimut >= 0) ? 1 : 2;
                DBG_DATA("%.2f,%.2f,%.2f,%.2f,%u,%u,%.6f,%.6f\n", Ecenit, Eazimut,Dcenit,Dazimut,speed_azimut,speed_cenit, outAzimut, outCenit);

                motors.move(dir_azimut, dir_cenit, speed_azimut, speed_cenit);
                vTaskDelay(sampleTime);
                deadZoneCounter = (fabs(Ecenit) <= deadZone && fabs(Eazimut) <= deadZone) ? deadZoneCounter + 1 : 0;
            }
            motors.stop();
            DBG_PRINTF("[CTRL] Zona muerta encontrada\n");
            endTick = xTaskGetTickCount();
            waitTicks = controlDelay - endTick + startTick;
            DBG_PRINTF("[CTRL] Ciclo completo: ejecucion = %lu ms, espera = %lu ms\n",
                    pdTICKS_TO_MS(endTick - startTick), pdTICKS_TO_MS(waitTicks));
            
            BaseType_t notified = xTaskNotifyWait(0x00, 0xFFFFFFFF, &notifiedValue, waitTicks);
            if (notified == pdTRUE) {
                if (notifiedValue == TASK_STOP_SIGNAL) {
                    DBG_PRINTF("[CTRL] Cambio de modo detectado.\n");
                    motors.stop();
                    goto wait_for_start; // vuelve a la espera del próximo START
                } else if (notifiedValue == TASK_UPDATE_INTERVAL) {
                    controlDelay = controlSync();
                    DBG_PRINTF("[CTRL] Nuevo intervalo: %lu ms\n", pdTICKS_TO_MS(controlDelay));
                }
            } else controlDelay = newControlInterval;
        }
        wait_for_start:;
    }
}

// *****************************************
//  TAREA ADMINISTRADOR DE TAREAS
// *****************************************
void taskManager(void *pvParameters) {
    uint32_t notifiedValue = 0;

    for (;;) {
        // Espera notificación para reevaluar el modo actual
        xTaskNotifyWait(0x00, 0xFFFFFFFF, &notifiedValue, portMAX_DELAY);

        DBG_PRINTF("[TYPE] Evaluando tipo de operación: %s\n", memory.operationType.c_str());
        newControlInterval = memory.controlInterval;

        // --- Control de tipos de operacion ---
        if (memory.operationType == "control") {
            // Solo control (sin sincronización)
            xTaskNotify(loggingTaskHandle, TASK_STOP_SIGNAL, eSetValueWithOverwrite);
            xTaskNotify(controlTaskHandle, TASK_UPDATE_INTERVAL, eSetValueWithOverwrite);
            DBG_PRINTF("[TYPE] Tipo CONTROL activado.\n");
        }
        else if (memory.operationType == "control-log") {
            // Log + control (con sincronización)
            xTaskNotify(loggingTaskHandle, TASK_UPDATE_INTERVAL, eSetValueWithOverwrite);
            xTaskNotify(controlTaskHandle, TASK_UPDATE_INTERVAL, eSetValueWithOverwrite);
            DBG_PRINTF("[TYPE] Tipo CONTROL + LOG activado.\n");
        }
        else if (memory.operationType == "sync") {
            // Corrección antes del registro (sincronizada)
            newControlInterval = memory.logInterval;
            xTaskNotify(loggingTaskHandle, TASK_UPDATE_INTERVAL, eSetValueWithOverwrite);
            xTaskNotify(controlTaskHandle, TASK_UPDATE_INTERVAL, eSetValueWithOverwrite);
            DBG_PRINTF("[TYPE] Tipo SYNC ejecutado.\n");
        }
        else {
            DBG_PRINTF("[TYPE] Tipo no reconocido: %s\n", memory.operationType.c_str());
        }
    }
}

// *****************************************
//  FUNCION PARA REPOSICIONAR EL SISTEMA
// *****************************************
void positionTask(void* pvParameters) {
    bool activeDetected = false;

    for (;;) {
        // Espera notificación desde la ISR
        ulTaskNotifyTake(pdTRUE, portMAX_DELAY);

        bool currentState = digitalRead(END_H);

        // Detectar flanco de subida (activación del final)
        if (currentState == HIGH && !activeDetected) {
            activeDetected = true;
            DBG_PRINTLN("Final de carrera horizontal ACTIVADO");
        }

        // Detectar flanco de bajada (ya pasó el límite)
        else if (currentState == LOW && activeDetected) {
            activeDetected = false;
            DBG_PRINTLN("Final de carrera horizontal DESACTIVADO -> pasó el límite");

            // Ajusta la dirección
            azimutDirection = memory.savePosition(!azimutDirection);

            DBG_PRINT("Dirección azimutal ajustada a: ");
            DBG_PRINTLN(azimutDirection ? "antihoraria" : "horaria");
        }
    }
}

// ************************
//  MODO HOMING
// ************************
void homingSequence() {
    xTaskNotify(ledTaskHandle, LED_HOMING, eSetValueWithOverwrite);
    isHoming = true;
    DBG_PRINTLN("Iniciando secuencia de homing...");
    
    // Mover motores hacia los finales de carrera
    while(digitalRead(START_V) == LOW) {
        motors.move(0, 2, 0, 80);       // Mover solo vertical hacia END_V
        vTaskDelay(pdMS_TO_TICKS(10));
    }
    motors.stop();
    DBG_PRINTLN("Final de carrera vertical alcanzado");
    
    if (azimutDirection) {
        while(digitalRead(END_H) == LOW) {
            motors.move(2, 0, 80, 0);       // Mover solo horizontal hacia END_H en sentido horario
            vTaskDelay(pdMS_TO_TICKS(10));
        }
    } else {
        while(digitalRead(END_H) == LOW) {
            motors.move(1, 0, 80, 0);       // Mover solo horizontal hacia END_H en sentido antihorario
            vTaskDelay(pdMS_TO_TICKS(10));
        }
    }
    
    motors.stop();
    DBG_PRINTLN("Final de carrera horizontal alcanzado");
    
    // Mover a posición inicial 
    if (azimutDirection) {
        motors.move(1, 0, 90, 0);
    } else {
        motors.move(2, 0, 90, 0);
    }          
    vTaskDelay(5000);                   // Tiempo suficiente para llegar horizontal
    motors.stop();
    motors.move(0, 1, 0, 90);           
    vTaskDelay(5000);                   // Tiempo suficiente para llegar vertical
    motors.stop();
    DBG_PRINTLN("Secuencia de homing completada");
    motors.mode = true;                 // Cambio a modo manual
    xTaskNotify(ledTaskHandle, LED_MANUAL, eSetValueWithOverwrite);
    DBG_PRINTLN("Modo cambiado a Manual después de homing");
    isHoming = false;
}

// ************************
//  NOTIFICACION DE MODO DE OPERACION
// ************************
void notifyMode(bool fromHardware) {
    motors.mode = !motors.mode;
    xTaskNotify(ledTaskHandle, motors.mode ? LED_MANUAL : LED_AUTOMATIC, eSetValueWithOverwrite);
    webInterface.broadcastMode(motors.mode);

    if (motors.mode) {
        xTaskNotify(controlTaskHandle, TASK_STOP_SIGNAL, eSetValueWithOverwrite);
        DBG_PRINTLN(fromHardware 
            ? "[BOTÓN] Pulsación corta (HW) → CAMBIO DE MODO A MANUAL" 
            : "[BOTÓN] Pulsación corta (SW) → CAMBIO DE MODO A MANUAL");
    } else {
        xTaskNotify(controlTaskHandle, TASK_START_SIGNAL, eSetValueWithOverwrite);
        DBG_PRINTLN(fromHardware 
            ? "[BOTÓN] Pulsación corta (HW) → CAMBIO DE MODO A AUTOMÁTICO" 
            : "[BOTÓN] Pulsación corta (SW) → CAMBIO DE MODO A AUTOMÁTICO");
    }
}

// *****************************************
//  GESTION DEL BOTON DE CAMBIO DE MODO
// *****************************************
void buttonTask(void *pvParameters) {
    const uint16_t longPressThreshold = 3000;     
    uint32_t notifyValue = 0;  

    for (;;) {
        // Espera evento (ya sea ISR o notificación desde otra tarea)
        xTaskNotifyWait(0x00, 0xFFFFFFFF, &notifyValue, portMAX_DELAY);

        // --- Pulsación (hardware físico) ---
        if (notifyValue == 1 && digitalRead(SET_MODE) == HIGH) {
            unsigned long pressStart = millis();

            // Esperar hasta que se suelte el boton
            while (digitalRead(SET_MODE) == HIGH) {
                if (millis() - pressStart >= longPressThreshold) {
                    DBG_PRINTLN("[BOTÓN] Pulsación larga → HOMING");
                    xTaskNotify(controlTaskHandle, TASK_STOP_SIGNAL, eSetValueWithOverwrite);
                    homingSequence();
                    break;
                }
                vTaskDelay(pdMS_TO_TICKS(50));
            }

            // Si fue corta, cambiar modo
            if (millis() - pressStart < longPressThreshold) {
                notifyMode(true);
            }
        }
        // --- Pulsación corta (software) ---
        else if (notifyValue == 2){
            notifyMode(false);
        }
    }
}

// ************************
//  GESTION DEL PILOTO INDICADOR
// ************************
void ledTask(void *pvParameters){
    uint32_t notifiedValue = 0;
    TickType_t onTime = pdMS_TO_TICKS(1000);
    TickType_t offTime = pdMS_TO_TICKS(4000);

    for (;;) {
        // Espera notificación para actualizar el modo
        if (xTaskNotifyWait(0x00, 0xFFFFFFFF, &notifiedValue, 0) == pdTRUE) {
            switch (notifiedValue) {
                case LED_AUTOMATIC: offTime = pdMS_TO_TICKS(4000); break;
                case LED_MANUAL:    offTime = pdMS_TO_TICKS(2000); break;
                case LED_HOMING:    offTime = pdMS_TO_TICKS(100); break; // parpadeo rápido
                default:            offTime = 0; digitalWrite(LED_PIN, LOW); break;
            }
        }

        // Encender LED
        digitalWrite(LED_PIN, HIGH);
        vTaskDelay(onTime);

        // Apagar LED
        digitalWrite(LED_PIN, LOW);
        if (offTime > 0) vTaskDelay(offTime);
    }
}


// ************************
//  INTERRUPCION HMI
// ************************
void IRAM_ATTR webServerISR() {
    static uint32_t lastInterruptTime = 0;
    uint32_t currentTime = millis();

    // Enviar notificación a la tarea
    if (currentTime - lastInterruptTime > 500) {
        lastInterruptTime = currentTime;
        BaseType_t xHigherPriorityTaskWoken = pdFALSE;
        xTaskNotifyFromISR(webControlHandle, 1, eSetValueWithOverwrite, &xHigherPriorityTaskWoken);
        portYIELD_FROM_ISR(xHigherPriorityTaskWoken);
        
    }
}

// ************************
//  INTERRUPCION DEL BOTON DE CAMBIO DE MODO 
// ************************
void IRAM_ATTR modeButtonISR() {
    static uint32_t lastInterruptTime = 0;
    uint32_t currentTime = millis();

    // Enviar notificación a la tarea
    if (currentTime - lastInterruptTime > 100) {
        BaseType_t xHigherPriorityTaskWoken = pdFALSE;
        xTaskNotifyFromISR(buttonTaskHandle, 1, eSetValueWithOverwrite, &xHigherPriorityTaskWoken);
        portYIELD_FROM_ISR(xHigherPriorityTaskWoken);
        lastInterruptTime = currentTime;
    }
}

// ************************
//  INTERRUPCIONES DE LOS FINALES DE CARRERA
// ************************
void IRAM_ATTR endCenitISR() {
    xTaskNotify(controlTaskHandle, TASK_STOP_SIGNAL, eSetValueWithOverwrite);
}

void IRAM_ATTR endAzimutISR() {
    static uint32_t lastInterruptTime = 0;
    uint32_t currentTime = millis();

    if (!isHoming && currentTime - lastInterruptTime > 1000){
        BaseType_t xHigherPriorityTaskWoken = pdFALSE;
        vTaskNotifyGiveFromISR(positionTaskHandle, &xHigherPriorityTaskWoken);
        portYIELD_FROM_ISR(xHigherPriorityTaskWoken);
        lastInterruptTime = currentTime;
    }
}
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
void loop() {

    delay(2000);
}

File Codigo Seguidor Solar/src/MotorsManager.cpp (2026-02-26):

#include "MotorsManager.h"

MotorsManager::MotorsManager(uint8_t pinH, uint8_t pwmH, uint8_t pinV, uint8_t pwmV)
    : _pinH(pinH), _pwmH(pwmH), _pinV(pinV), _pwmV(pwmV) {}

void MotorsManager::begin() {
    pinMode(_pinH, OUTPUT); 
    pinMode(_pinV, OUTPUT);
    ledcSetup(_channelH, _freq, _resolution); 
    ledcAttachPin(_pwmH, _channelH);
    ledcSetup(_channelV, _freq, _resolution); 
    ledcAttachPin(_pwmV, _channelV);
    stop();
}

void MotorsManager::move(uint8_t dirH, uint8_t dirV, uint8_t speedH, uint8_t speedV) {
    // dir = 1 FORWARD, dir = 2 BACKWARD, dir = 0 STOP
    _setMotor(_pinH, _channelH, dirH, speedH, dirH == 1 ? offsetH_right : offsetH_left); // Eje horizontal
    _setMotor(_pinV, _channelV, dirV, speedV, dirV == 1 ? offsetV_up : offsetV_down); // Eje vertical
}

void MotorsManager::_setMotor(uint8_t pin1, uint8_t channel, uint8_t dir, uint8_t speed, uint8_t offset) {
    digitalWrite(pin1, dir == 1 ? HIGH : LOW);
    if (speed != 0){
        ledcWrite(channel, map(speed, 1, 100, offset*2.55, 255));
    } else ledcWrite(channel, 0);
}

void MotorsManager::stop(){
    move(0, 0, 0, 0); 
}

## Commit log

2026-02-26 Primer commit
    [4mm Black Banana Female Socket Jack Mount Connectors.step, 4mm Red Banana Female Socket Jack Mount Connectors.step, Button Yellow.SLDPRT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]
2026-02-26 Segundo commit
    [electronicBoard.kicad_pcb, electronicBoard.kicad_sch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]
2026-03-05 Tercer commit
    [electronicBoard.kicad_pcb, electronicBoard.kicad_sch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]
